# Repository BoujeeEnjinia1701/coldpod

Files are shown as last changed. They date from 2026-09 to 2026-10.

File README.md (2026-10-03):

# ColdPod

     

**Area:** BioMedical · **TRL:** 3 of 9 (proof of concept on paper) · **Value-engineering target:** $310 USD (hypothetical control target; estimated cost of the constructable design $313, $3 over the target) · **Difficulty:** 3 of 5

Portable Peltier cooler with a phase-change buffer and a temperature logger that raises alerts on excursions.

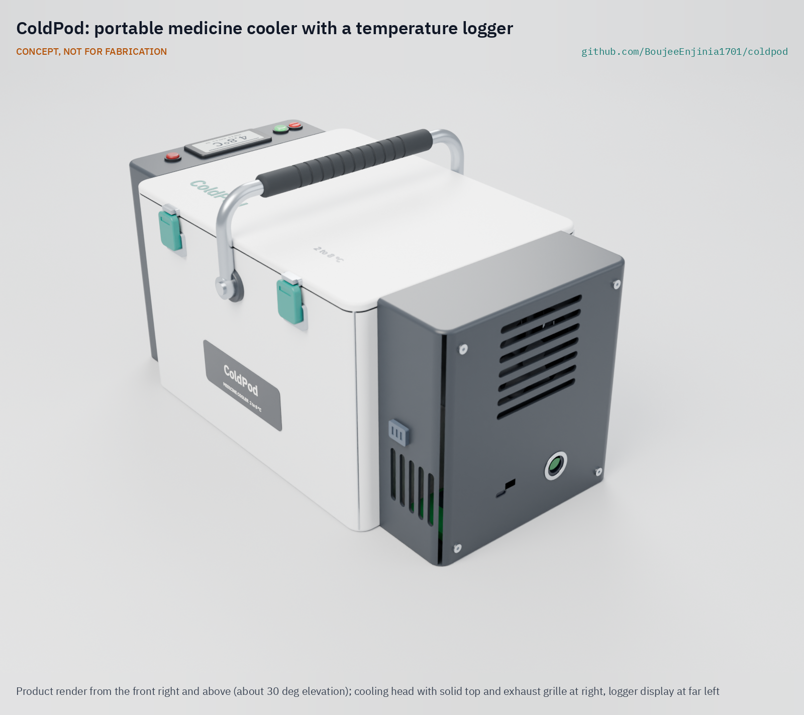
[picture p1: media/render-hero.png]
ColdPod: portable medicine cooler with a temperature logger, product render


[Exploded render](media/render-exploded.png) · [Detail render](media/render-detail.png) · [Interactive 3D model](media/viewer.html) · [Concept blueprint (PDF)](media/concept-blueprint.pdf) · [General arrangement CPD-DWG-001 (PDF)](cad/drawings/CPD-DWG-001.pdf) · [Sizing calculations](docs/04-calcs/01-sizing.md) · [Prototype build plan](docs/05-build-plan.md) · [Design decisions](docs/06-design-decisions.md) · [Review note](docs/REVIEW.md)

## Concept rationale

A vaccine or insulin carrier has to solve two problems at once: it must not let the load warm up, and it must not let it freeze. Ice packs solve the first badly and cause the second. ColdPod stores its cold in a phase-change material that melts at 5 °C, so the coldest thing next to the payload is still inside the 2 to 8 °C window. A small Peltier module recharges that store from a vehicle socket, a solar panel or a USB-C charger instead of a freezer, and a one-way thermosiphon stops the module from leaking heat back in when it is off. A logger with its own alarms records what the payload actually saw, so a health worker knows whether a load is still good.

It is open and garage-buildable because the gap is not the physics but access. Commercial active carriers exist, but they are closed products that a clinic, a university group or a maker space cannot inspect, repair or adapt. ColdPod uses printed parts, bought vacuum-insulated panels, off-the-shelf power modules and no custom circuit board, and it publishes its heat-leak, hold-time and fault calculations so that anyone can check them.

## Burning platform

Two very large groups depend on a cold chain that often fails at its last step. There are 589 million adults living with diabetes, 81 % of them in low- and middle-income countries ([IDF Diabetes Atlas, 11th edition, 2025](https://media.idf.org/media/uploads/sites/3/2025/04/IDF_Atlas_11th_Edition_2025_Global-Factsheet.pdf)), and many of those who use insulin must keep it at 2 to 8 °C and discard it if it freezes ([US FDA](https://www.fda.gov/drugs/emergency-preparedness-drugs/information-regarding-insulin-storage-and-switching-between-products-emergency)). Routine immunization still leaves 14.3 million infants a year without a single vaccine dose, half of them in countries affected by fragility, conflict or humanitarian crises, where carrying vaccines is hardest ([WHO and UNICEF, 2025](https://www.unicef.org/press-releases/global-childhood-vaccination-holds-steady-yet-over-14-million-infants-remain)).

Freezing, not only heat, is a common failure. A systematic review estimated that vaccines were exposed to temperatures below the recommended range in about 33 % of storage in wealthier countries and 37 % in lower-income countries, and in about 38 % and 19 % of shipments ([Hanson et al., *Vaccine*, 2017](https://www.sciencedirect.com/science/article/pii/S0264410X16309471)). Many of these events are never recorded, because the carrier has no logger.

## Where it could be used

### By industry

| Industry | Use |
| --- | --- |
| Public health and immunization programs | Outreach sessions on foot, bicycle or motorbike, with a record that the day's vaccines stayed in range |
| Humanitarian and disaster response | Insulin and vaccines carried where the grid is down, recharged from vehicles or solar panels |
| Community pharmacy and home delivery | Temperature-sensitive medicines delivered by van or motorbike with a trip log |
| Diabetes care and patient support | Travel and power-cut backup for people who carry a month of insulin |
| Clinical research and sample logistics | Short transfers of 2 to 8 °C research materials with a logged temperature history |
| Global health engineering education | An open, auditable reference design for cold chain teaching and research |

### By country or region

| Country or region | Why it matters there |
| --- | --- |
| Sub-Saharan Africa | Long outreach trips in heat with intermittent clinic power; WHO measures a vaccine carrier's cold life at a constant ambient temperature of 43 °C ([WHO PQS E004/VC01.2](https://extranet.who.int/pqweb/key-resources/documents/pqs-performance-specification-e004vc012-vaccine-carrier)) |
| South Asia | Very hot pre-monsoon seasons and dense rural outreach; the region is part of the low- and middle-income world where 81 % of adults with diabetes live ([IDF, 2025](https://media.idf.org/media/uploads/sites/3/2025/04/IDF_Atlas_11th_Edition_2025_Global-Factsheet.pdf)) |
| Countries affected by conflict or humanitarian crisis | Half of all unvaccinated children live in 26 fragile or crisis-affected countries ([WHO and UNICEF, 2025](https://www.unicef.org/press-releases/global-childhood-vaccination-holds-steady-yet-over-14-million-infants-remain)), where cold chain equipment and power are least reliable |
| Latin America, including the Amazon basin | In Colombia's Putumayo department, vaccination teams travel five to six hours by river to reach riverside communities ([PAHO, 2024](https://www.paho.org/en/stories/colombian-vaccination-team-donated-boat-makes-all-difference)), and in Panama some communities can be reached only by plane or boat ([PAHO](https://www.paho.org/en/stories/strengthening-cold-chain-operations-mission-take-vaccines-farthest-corners-region)) |
| United States and other high-income countries | Natural disasters and other emergencies can leave people with insulin but no working refrigerator; the FDA publishes storage guidance for these conditions ([US FDA](https://www.fda.gov/drugs/emergency-preparedness-drugs/information-regarding-insulin-storage-and-switching-between-products-emergency)), and freezing in storage is common even in wealthier countries ([Hanson et al., 2017](https://www.sciencedirect.com/science/article/pii/S0264410X16309471)) |

## What sparked the idea

The starting point was the vaccine vial monitor, the heat-sensitive label that WHO and PATH brought into use on oral polio vaccine in 1996 ([PATH](https://www.path.org/our-impact/articles/vaccine-vial-monitor-worlds-smartest-sticker/)). It showed that a cheap indicator travelling with each vial could change field practice, but it records only cumulative heat: training material for health workers states that vial monitors "do not measure exposure to freezing temperatures" and that a frozen vaccine may have lost its potency without the monitor showing it ([OpenLearn Create, Immunization module](https://www.open.edu/openlearncreate/mod/oucontent/view.php?id=53354&section=1.5.1)). ColdPod takes the next step for the carrier itself: prevent freezing by design, and log and alarm on both heat and cold.

## Problem

Insulin and vaccines spoil in field transport without a reliable cold chain. They must stay between 2 and 8 °C: ice packs run out in the heat, freeze vials when they are too cold, and usually nothing records what happened. Studies of the vaccine cold chain find freezing exposure in roughly a fifth to a third of storage and shipping studies. Design with, not for: requirements must come from co-design with health workers and people who carry insulin, through a local partner.

Full problem statement: [docs/01-problem.md](docs/01-problem.md)

## Concept

A carry case 366 x 220 x 207 mm holds 1.37 L of insulin or vaccines (24 insulin pens) in an aluminium liner wrapped in a phase-change material that melts at 5 °C, inside 25 mm vacuum-insulated panels. A Peltier module refreezes the phase-change material from a 12 V socket, a solar panel or a USB-C charger, through a loop thermosiphon that carries heat one way only; an aluminium cold plate tray round the lid pack lets it freeze that pack too. A 76.8 Wh LiFePO4 battery keeps it cooling on the road, and a logger records the payload temperature every minute and raises alarms on excursions.

TRL 3 calculations ([CPD-CAL-001](docs/04-calcs/01-sizing.md)): about 13.3 h with no power at 43 °C, 27.3 h off-grid at 32 °C and 16.7 h off-grid at 43 °C, all with thin margins. Two hardware cut-outs in series keep a stuck-on driver from freezing the payload. Refreezing all the phase-change material takes 8.0 h, within the 9 h overnight target, and the case weighs 5.74 kg empty now that every fixing is in, within the 5.75 kg prototype limit; Amish set both targets on 2026-10-02 ([design decisions register](docs/06-design-decisions.md)). Value-engineering target: USD 310 (a hypothetical control target, not a limit). Estimated cost of the constructable design: USD 313 (USD 3 over the target). TRL 4 (lab testing) is on hold.

Full design precis: [docs/02-concept.md](docs/02-concept.md)

## Key components

- Vacuum-insulated panels, 25 mm, in a printed shell
- Phase-change material packs, 5 °C, around an aluminium liner
- Aluminium evaporator can and loop thermosiphon (one-way) to a 40 mm Peltier module (TEC1-12703 class)
- Aluminium lid cold plate tray holding the lid phase-change pack
- Heat sink and fan in a vented cooling head
- LiFePO4 battery, 12.8 V 6 Ah (76.8 Wh), with BMS
- USB-C PD and 12 V power board with a buck-boost Peltier driver and two hardware freeze cut-outs (cold block and liner)
- nRF52840 logger with buffered payload probe, e-paper display and alarm

The working bill of materials is in [bom/bom.csv](bom/bom.csv).

## Building the prototype

The design is constructable: every part can be printed, folded, bent, machined or bought, and every part fixes to the next. Because a vacuum-insulated panel sits behind every wall, no screw goes through the shell; all outside fixings land on printed pads with threaded inserts. The [prototype build plan](docs/05-build-plan.md) shows each of the 15 made components on a making sketch and every one of the 20 assembly steps in a picture; the sealed copper loop is brazed and charged by a refrigeration technician before it goes in. It is a plan, not yet built; building to it is TRL 4 work.

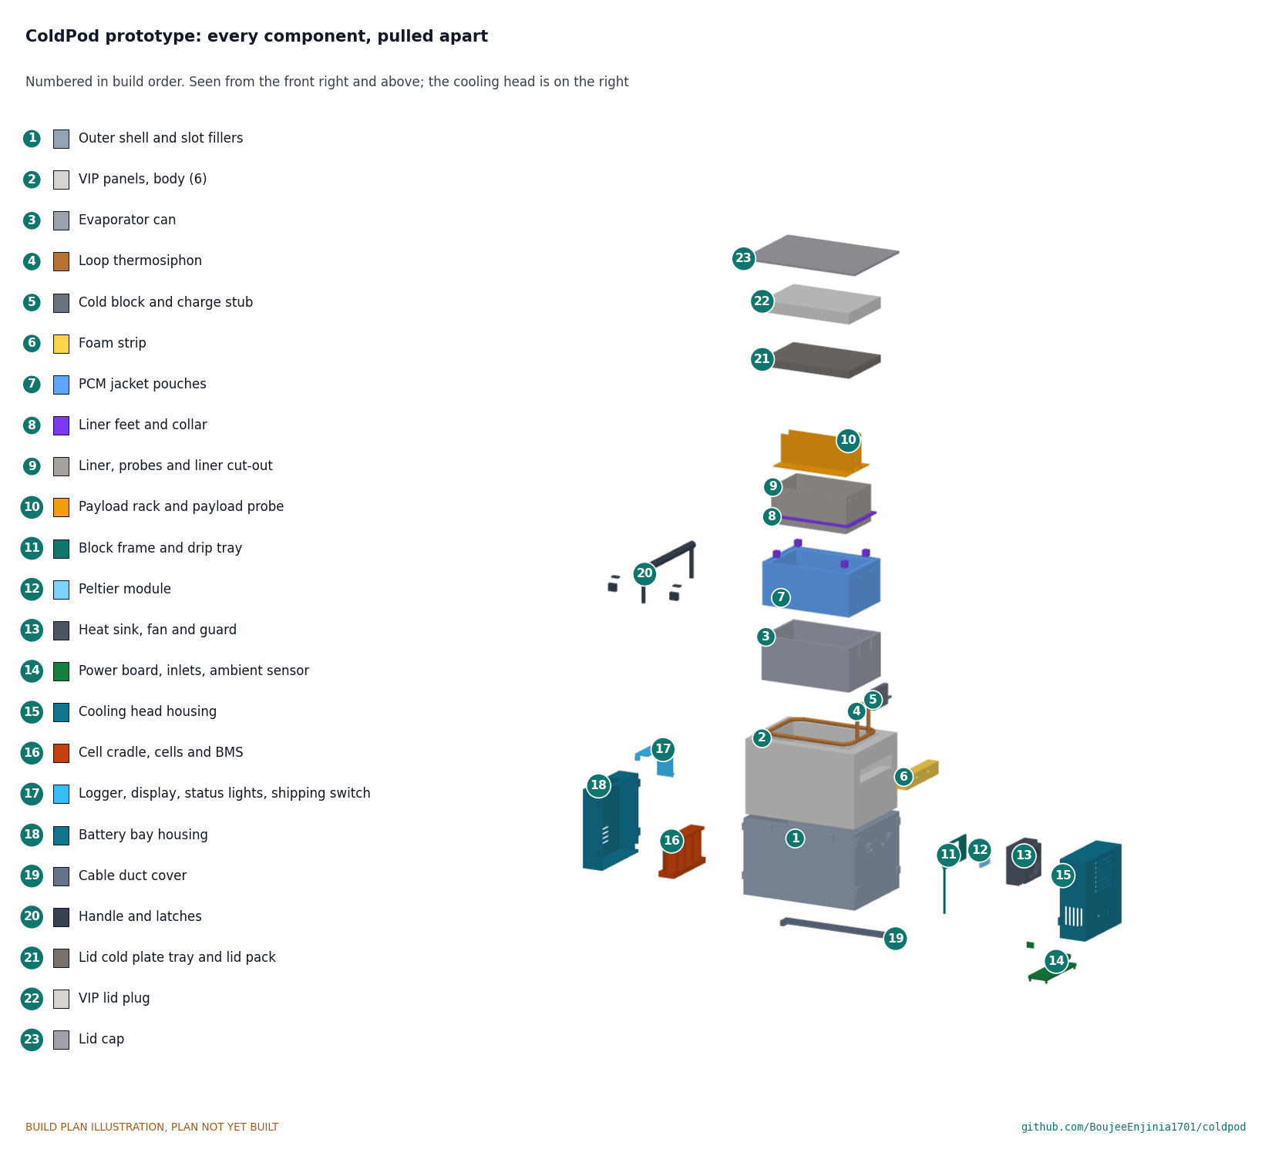
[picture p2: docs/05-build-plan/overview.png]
ColdPod prototype: every component, pulled apart and numbered in build order


## Safety

> This is a research and educational prototype. It is not a medical device, has not been cleared or approved by any regulator, is not WHO-prequalified, and must not be used to diagnose, treat or monitor any person or as the only protection for real vaccines or insulin.

It contains a lithium (LiFePO4) battery, a combustible paraffin phase-change material and a heat sink that can get hot. See the safety section of the [design precis](docs/02-concept.md#safety).

## Repository layout

| Folder | Contents |
| --- | --- |
| `docs/` | Problem, concept, requirements, calculations (`04-calcs/`) and design decisions (`decisions/`) |
| `cad/src/` | build123d Python source, the source of truth for all geometry |
| `cad/step/`, `cad/stl/` | Exported models for FreeCAD, other CAD tools and printing |
| `cad/drawings/` | 2D sketches and dimensioned drawings |
| `bom/` | Bill of materials |
| `electronics/` | KiCad schematics and PCB layouts |
| `firmware/` | Microcontroller code |
| `media/` | Renders, perspectives and photos |
| `build-log/` | Dated prototyping notes |

## Documentation

Controlled documents follow the portfolio [documentation standard](.kit/STANDARDS.md). Each carries a document ID (CPD-PRC-001 for the precis), a version and a revision history. Branded PDFs are built with `python .kit/render.py` and attached to GitHub Releases when a document is tagged, for example `CPD-PRC-001/v1.0`.

## Credits

Designed by Amish Chadha, with contributions from Dr. Geeti Chadha. See [CONTRIBUTORS.md](CONTRIBUTORS.md) for roles. To cite this design, use [CITATION.cff](CITATION.cff) (GitHub shows it as "Cite this repository").

AI assistance (Claude) was used to accelerate concept renders, prototype documentation and first-pass sizing calculations. Design direction and all decisions are Amish Chadha's, recorded in this repository's decision records (`docs/decisions/`).

## Licenses

- **Hardware** (CAD, drawings, BOM, electronics): [CERN-OHL-S v2](LICENSE)
- **Software** (firmware, scripts, notebooks): [MIT](LICENSE-SOFTWARE)

A project of the [Design Molecule](https://designmolecule.com) lab.

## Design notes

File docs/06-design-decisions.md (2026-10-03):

---
doc_id: CPD-DEC-001
title: ColdPod design decisions register
project: ColdPod
doc_type: Design decisions register
version: "0.5"
status: Draft
date: '2026-10-03'
author: Amish Chadha
license: CERN-OHL-S-2.0
revisions:
  - version: "0.1"
    date: '2026-10-01'
    author: Amish Chadha
    change: Register opened with the open decisions from the review note, the decision records and the build plan work
  - version: "0.2"
    date: '2026-10-01'
    author: Amish Chadha
    change: Budget treated as a value-engineering target
  - version: "0.3"
    date: '2026-10-02'
    author: Amish Chadha
    change: "Amish approved the recommendations for open decisions 1 to 7 (2026-10-02); moved to decisions made (CPD-DDR-003 accepted)"
  - version: "0.4"
    date: '2026-10-02'
    author: Amish Chadha
    change: "Value engineering restated after the approved follow-ups were carried into the model and BOM: USD 313, USD 3 over the target (battery shipping switch added)"
  - version: "0.5"
    date: '2026-10-03'
    author: Amish Chadha
    change: "Amish accepted the cost overrun against the value-engineering target on 2026-10-03; row added to decisions made; value engineering section updated"
---

# ColdPod design decisions register

Every design decision still to be made, and every decision made, in one place. Each decision is argued in full in its decision record under `docs/decisions/`; this register is the index Amish works from. The build plan (`docs/05-build-plan.md`) describes the design as it stands and does not list open decisions.

## Open decisions

None. All open decisions were decided on 2026-10-02.

## To confirm when parts are bought

| # | What to confirm | Why it matters | Source |
| --- | --- | --- | --- |
| 1 | The VIP maker can supply the seven panels to plus 0, minus 1 mm, with a quote and aged conductivity and edge data | The panels fill the shell exactly; joints and edges are about 45 % of the heat leak | CPD-DDR-003; CPD-CAL-001 |
| 2 | The gasket still seals with the lid tray landed on the can flange, and the tray seat gives about 0.5 K/W | Lid seal and lid-pack refreeze both rest on it | CPD-DDR-002; CPD-CAL-001 |
| 3 | The PCM maker can supply the eight pouch shapes, and the usable latent heat between 2 and 8 °C | Pouch fit round the risers and feet; hold times | CPD-DDR-003; CPD-CAL-001 |
| 4 | The bought handle's pivot eyes take M5 screws and clear the 4 mm pads | Handle pivot pads | CPD-DDR-003 |
| 5 | The off-state conductance and real COP of the chosen module with the chosen heat sink and fan | Hold power and the thermosiphon diode ratio | CPD-PRC-001 |
| 6 | The Peltier driver can run the module from a 10 V input | R7 at the low end of the vehicle range | CPD-DDR-002 |
| 7 | Whether a motorbike carrier stays within about 19° of tilt with the cooling head down; if not, the mechanical disconnect fallback | The loop thermosiphon works only below that tilt | CPD-DDR-001, D2; CPD-CAL-001, H5 |

## Value engineering

Value-engineering target: USD 310 (a hypothetical control target, not a limit). Estimated cost of the constructable design: USD 313 (USD 3 over the target).

Amish accepted this overrun on 2026-10-03: the estimated cost of USD 313 against the USD 310 target (USD 3 over), keeping the USD 5 battery shipping switch (BOM line 18). Amish: "Cost over target - i accept all the cost variations and overruns". It stays reported against the target as an accepted overrun, and the savings below remain worth trying.

- **Main cost drivers:** the vacuum-insulated panel set (about USD 60, still an estimate until quoted), the thermosiphon loop (about USD 28), the buck-boost Peltier driver (USD 22 to 26), the lid cold plate tray (USD 13) and the liner cut-out (USD 10 to 13).
- **Savings worth trying:** a VIP quote before any purchase; thinner printed parts, which already saved about USD 4 of filament; and re-pricing the driver and thermosiphon parts at purchase; the USD 5 shipping switch could wait until a trip needs it, which would bring the cost back to USD 308.

## Decisions made

| Date | Decision | Decided by | Record |
| --- | --- | --- | --- |
| 2026-09-25 | TRL 2 review items D1 to D11: 5 °C organic PCM, thermosiphon with a mechanical disconnect as fallback, evaporator on the outer face of the PCM, 76.8 Wh LiFePO4 pack, R6 redefined to 16 h, R12 relaxed to 5.5 kg, VIPs with a foam variant documented, local alarms and Bluetooth only, alarm defaults, budget $300, outreach vaccinators first | Amish, going with the recommendation | CPD-DDR-001 |
| 2026-09-25 | TRL 3 recommendations: lid cold plate, 3 °C liner cut-out, thinner printed parts, evaporator can and loop thermosiphon, TEC1-12703 class with smooth DC, buck-boost driver, budget kept at $300 | Amish: "i accept all your recommendations, go with them across all repos." | CPD-DDR-002 |
| 2026-09-26 | Budget top-up to $310 (R15 met) | Amish: "I am ok with the budget top ups" | CPD-DDR-002, N3 |
| 2026-09-30 | Make the design physically buildable while drawing the build plan | Amish: "If you are realising that the design cannot be built as per concept - fix the design assumptions to match and be physically feasible as you draw the illustrations." The changes themselves were accepted on 2026-10-02 (below) | CPD-DDR-003 |
| 2026-10-02 | Design for construction accepted: the changes P1 to P12 (pads and towers on the shell, rim slots, foam strip, loop in the can corner, block frame, liner feet and collar, folded lid tray, fixings, drip tray, cable duct) and their knock-on changes, as made | Amish: "i approve your recommendations for all 555 open decisions." | CPD-DDR-003, A1 |
| 2026-10-02 | Mass (R12): option (a). R12 relaxed to 5.75 kg for the prototype, which is weighed at TRL 4; the base bumper is left off so the 0.05 kg margin is not spent before weighing | Amish: "i approve your recommendations for all 555 open decisions." | CPD-DDR-003, A2; CPD-DDR-002, N2 |
| 2026-10-02 | Refreeze (R8): option (a). R8 restated as 9 h or less for all the PCM at 25 °C, still an overnight refreeze | Amish: "i approve your recommendations for all 555 open decisions." | CPD-DDR-002, N1; CPD-CAL-001 v0.4, G4 |
| 2026-10-02 | Battery removal (R14): option (a) for the prototype; the battery bay on four screws counts as removable. Before any field or air travel use, add the shipping switch and check the carrier's lithium battery rules. The switch is now in the model and the BOM (line 18, USD 5), which took the cost from USD 308 to USD 313 | Amish: "i approve your recommendations for all 555 open decisions." | CPD-DDR-003, A3 |
| 2026-10-02 | Loop working fluid: R-134a (non-flammable, safety class A1) for the prototype, with the charge set by the refrigeration technician from the loop volume; a lower-impact fluid such as R-1234yf (A2L, mildly flammable) is revisited only for a product version and under local rules | Amish: "i approve your recommendations for all 555 open decisions." | CPD-DDR-003, A4 |
| 2026-10-02 | Co-design partner: an immunization program, consistent with outreach vaccinators first (CPD-DDR-001, D11). First candidate to approach: PATH, or a national immunization program's outreach team reached through it | Amish: "i approve your recommendations for all 555 open decisions." | CPD-DDR-001, O1 |
| 2026-10-02 | Appearance model: round bail in the model; heat sink kept solid (no window); second status light adopted; labels and wordmark under BOM line 16; base bumper left out until the prototype is weighed | Amish: "i approve your recommendations for all 555 open decisions." | `docs/REVIEW.md`, 2026-09-26 |
| 2026-10-03 | Cost overrun accepted: the estimated cost of USD 313 against the USD 310 target (USD 3 over), keeping the USD 5 battery shipping switch (BOM line 18) | Amish: "Cost over target - i accept all the cost variations and overruns" | [REVIEW.md](REVIEW.md), session 2026-10-03 |

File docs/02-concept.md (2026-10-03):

---
doc_id: CPD-PRC-001
title: ColdPod design precis
project: ColdPod
doc_type: Design precis
version: "0.9"
status: Draft
date: '2026-10-02'
author: Amish Chadha
license: CERN-OHL-S-2.0
revisions:
- version: "0.1"
  date: '2026-09-24'
  author: Amish Chadha
  change: Initial scaffold
- version: "0.2"
  date: '2026-09-25'
  author: Amish Chadha
  change: Populate to TRL 2 (architecture, first-order numbers, design choices, safety, media)
- version: "0.3"
  date: '2026-09-25'
  author: Amish Chadha
  change: Record Amish's decisions (CPD-DDR-001); numbers replaced by CPD-CAL-001; evaporator can, loop thermosiphon and TEC1-12703 class sized; smooth DC drive
- version: "0.4"
  date: '2026-09-25'
  author: Amish Chadha
  change: Recommendations accepted by Amish (DDR-002). Lid cold plate, liner cut-out at 3 °C, thinner printed parts and buck-boost driver; numbers from CPD-CAL-001 v0.2
- version: "0.5"
  date: '2026-09-26'
  author: Amish Chadha
  change: Budget top-up approved by Amish; budget $310, R15 met
- version: "0.6"
  date: '2026-10-01'
  author: Amish Chadha
  change: Constructable design (CPD-DDR-003, Draft, open for Amish's review); numbers from CPD-CAL-001 v0.4; build plan CPD-BLD-001 and decisions register CPD-DEC-001 added
- version: "0.7"
  date: '2026-10-01'
  author: Amish Chadha
  change: Budget treated as a value-engineering target
- version: "0.8"
  date: '2026-10-02'
  author: Amish Chadha
  change: "Decisions of 2026-10-02: CPD-DDR-003 accepted; R8 restated as 9 h and R12 relaxed to 5.75 kg; R-134a and battery removal safety rules; first partner candidate"
- version: "0.9"
  date: '2026-10-02'
  author: Amish Chadha
  change: "Figures from CPD-CAL-001 v0.7: 5.74 kg, $313 ($3 over the value-engineering target); battery shipping switch (item 18) and second status light added to the model and BOM"
---

# ColdPod design precis

ColdPod is a carry case about the size of a lunch cooler (366 x 220 x 207 mm) that holds 1.37 L of insulin or vaccines (24 pens) at 2 to 8 °C. The payload sits in an aluminium liner wrapped in a phase-change material (PCM) that melts at 5 °C, inside 25 mm vacuum-insulated panels. A Peltier module freezes the PCM from a 12 V socket, a solar panel or a USB-C charger, and a small LiFePO4 battery keeps it running on the road. A two-phase loop thermosiphon connects the two and carries heat in one direction only, so a stopped Peltier does not leak heat back in. A logger records the payload temperature every minute and raises alarms. An aluminium cold plate tray holding the lid PCM pack lands on the evaporator can's rim flange when the lid closes, so the Peltier freezes all the PCM, and a second hardware cut-out on the liner stops a stuck-on driver from freezing the payload. Version 0.6 describes the constructable design of CPD-DDR-003 (Draft, open for Amish's review), in which every part can be made and fixed; the prototype build plan is CPD-BLD-001 and open decisions are in the register CPD-DEC-001. The TRL 3 calculations (CPD-CAL-001 v0.7) give about 13.3 h with no power at 43 °C, 27.3 h off-grid at 32 °C and 16.7 h off-grid at 43 °C, for $313 in parts and 5.74 kg empty. The hold times meet their targets with thin margins. Refreezing all the PCM takes 8.0 h and the case weighs 5.74 kg; on 2026-10-02 Amish restated R8 as 9 h and relaxed R12 to 5.75 kg for the prototype, so both are met on paper (R12 with 0.05 kg of margin, to be weighed at TRL 4). The parts cost is within the $310 budget that Amish approved on 2026-09-26 (R15 met).

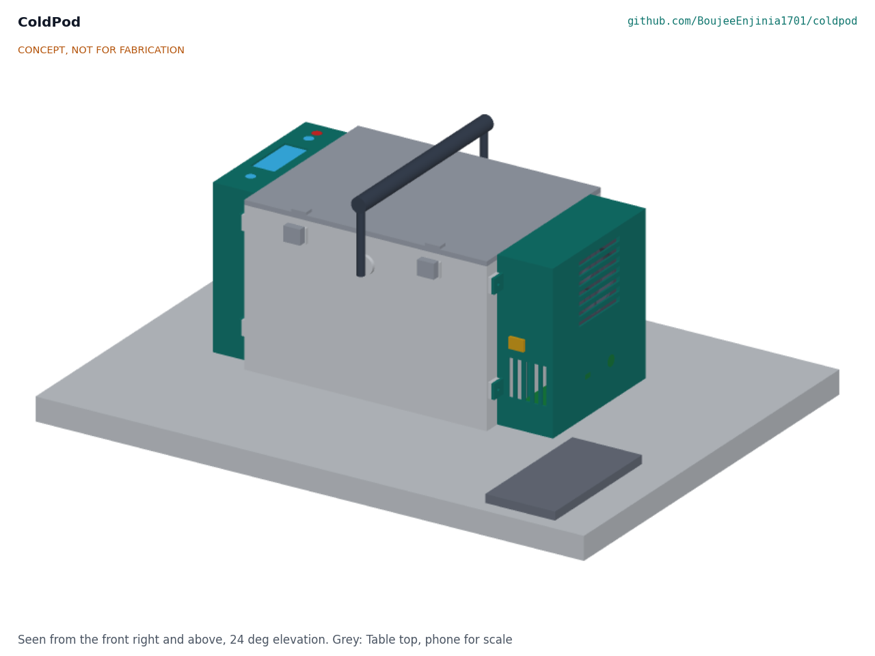
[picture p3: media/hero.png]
Hero render


*Figure 1. ColdPod on a table, with a phone for scale. Cooling head on the right end, battery and electronics bay with the e-paper display on the left end. Rendered from the parametric model `cad/src/model.py`.*

## How it works

1. **Charge the cold.** At a clinic, in a vehicle or under a solar panel, the Peltier module runs at up to 25 W and freezes the PCM jacket through the thermosiphon and the aluminium evaporator can around it. The lid PCM pack sits in a 1.5 mm aluminium cold plate tray that lands on the can's rim flange when the lid closes, so it freezes through the can too. The same input charges the battery at about 12 W. A fully melted charge refreezes in about 8.0 h (the jacket in 6.8 h). The case works best if the payload goes in already cold from a refrigerator.
2. **Carry.** On the road, the controller runs the Peltier from the battery only as hard as needed to hold the evaporator can at about 2 °C, so the PCM stays frozen, and turns it off when the battery reaches 15 % so that the logger always has a reserve. A buck-boost driver feeds the module smooth DC from any input between 10 and 20 V; on/off PWM would cost about 60 % more power at 43 °C. The lid pack stays frozen on its plate.
3. **Hold passively.** When the battery is flat or the user switches cooling off, the PCM absorbs the heat that leaks through the walls; the plate lets the jacket and lid pack share the load. Because it melts at 5 °C, it cannot pull the payload below freezing the way water ice can.
4. **Watch.** A buffered probe among the payload, a liner probe, a cold-block probe and an ambient sensor are read every minute. The payload probe is logged with a timestamp on the controller's flash memory for 60 days or more.
5. **Alarm.** The display shows current, minimum and maximum temperature and time left. A buzzer, an LED and a phone notification warn after 10 min outside 2 to 8 °C, alarm at once at 0 °C or lower, and flag low battery, a failed sensor or a lid left open. The owner exports the log as a CSV file over Bluetooth Low Energy or USB. Nothing goes to the cloud.

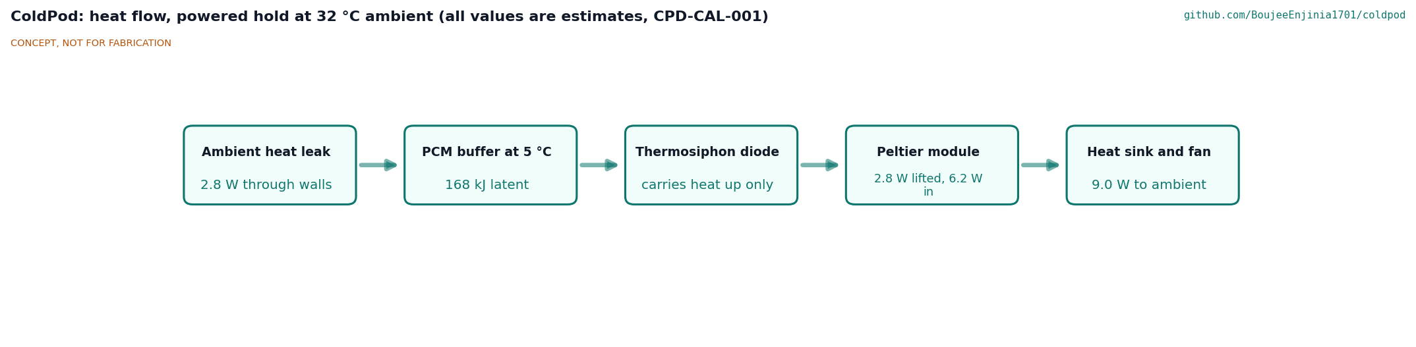
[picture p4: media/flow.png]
Heat flow


*Figure 2. Heat flow in powered hold at 32 °C ambient, can at 2 °C. All values are estimates from CPD-CAL-001: 0.092 W/K overall heat leak, TEC1-12703 class module at a coefficient of performance (COP) of 0.45, fan 0.6 W.*

## Main components

Table 1. Main components. Numbers match `bom/bom.csv` and Figure 4.

| # | Component | Proposed choice | Notes |
| --- | --- | --- | --- |
| 1 | Outer shell | 3D-printed PETG or ASA tub, 3 mm walls, 261 x 196 x 164.5 mm, with printed pads and towers carrying threaded inserts for every outside fixing, and pipe and cable slots closed by printed fillers | Protects the VIPs from knocks and punctures; no fixing passes through a wall (CPD-DDR-003) |
| 2 | Lid and lid cold plate | Printed 5 mm cap with EPDM gasket and a 25 mm VIP plug; 1.5 mm aluminium cold plate tray, 204 x 139 x 16.5 mm, holding the lid PCM pack and bonded to the plug | Two front draw latches; lid switch for the lid-open alarm; the tray lands on the can's rim flange so the lid pack freezes and stays frozen |
| 3 | Bail handle and strap | Folding bail handle, padded shoulder strap | Rated 10 kg or more |
| 4 | Vacuum-insulated panels | Seven panels, 25 mm, fumed silica core, ordered to size, and a 28 mm foam strip | VIPs cannot be cut or pierced; the heat-pipe crossing is a foam-filled gap between panels |
| 5 | PCM packs | About 0.94 kg of organic PCM melting at 5 °C (Rubitherm RT 5 HC class) in sealed HDPE pouches: a 0.67 kg jacket on four sides and the floor inside the evaporator can, and a 0.27 kg pack in the lid tray | Organic paraffins are stable for thousands of cycles ([PATH PCM study](https://media.path.org/documents/DT_pcm_summary_rpt1.pdf)) |
| 6 | Liner and rack | 1.5 mm aluminium can, 175 x 110 x 80 mm outside (172 x 107 x 78.5 mm inside), with a removable printed rack for 24 pens in four layers of six; stands on printed feet with a printed collar, never touching the can | Spreads cold evenly around the payload |
| 7 | Evaporator can and thermosiphon | 1.0 mm aluminium can lining the outer face of the PCM jacket (four sides and floor); two-phase loop thermosiphon: 8 mm copper evaporator loop bonded into the bottom corner of the can, vapour riser and liquid return at the +X end, stainless sections through the wall, aluminium cold block 81 mm above the loop, held to the shell by a printed frame | One-way thermal link (design choices 2 and 3); sized in CPD-CAL-001, section G |
| 8 | Peltier module | 40 x 40 mm, 127 couples, Imax about 3 A (TEC1-12703 class) | The TEC1-12706 cannot hold at 43 °C: its off-state conduction is too high (CPD-CAL-001, section E) |
| 9 | Heat sink and fan | Finned aluminium sink, 80 x 80 x 30 mm, 0.50 K/W or better with a 70 mm, 12 V fan and a finger guard | Rejects about 8.9 W at 32 °C and 19.7 W at 43 °C |
| 10 | End housings | Printed cooling head (+X end) and battery and electronics bay (−X end), 2 mm walls, vented | Keep the heat source and the battery outside the insulation |
| 11 | Battery | LiFePO4, 4S1P 32700 cells, 12.8 V 6 Ah (76.8 Wh), BMS and fuse | Below the 100 Wh airline limit |
| 12 | Power board | USB-C PD sink (20 V), 12 V input (10 to 15 V) with reverse-polarity protection, LiFePO4 charger, buck-boost Peltier driver with an LC filter, fan driver; the cold-block and liner cut-outs wired in series in the Peltier supply | Off-the-shelf modules on perfboard; no custom PCB |
| 13 | Logger controller | nRF52840 module with real-time clock and 2 MB flash | Bluetooth Low Energy link to a phone |
| 14 | Temperature sensors and liner cut-out | Glycol-buffered payload probe, liner probe, cold-block probe, ambient sensor; bimetal cut-out on the liner opening at 3 °C | Digital sensors with ±0.5 °C or better accuracy; the cut-out works without firmware |
| 15 | Display and alarm | 2.13 in e-paper, buzzer, two status lights (green and red, mirrored either side of the display) | E-paper keeps the last reading visible with no power |
| 18 | Battery shipping switch | Panel-mount rotary isolator, flush in the bay top, in series with the pack positive lead ahead of the fuse | Isolates the pack before any field or air travel (decided 2026-10-02) |

Item 16 (wiring, fasteners, latches and consumables) is in the BOM but not modelled; item 17 (printed construction parts) is in the model.

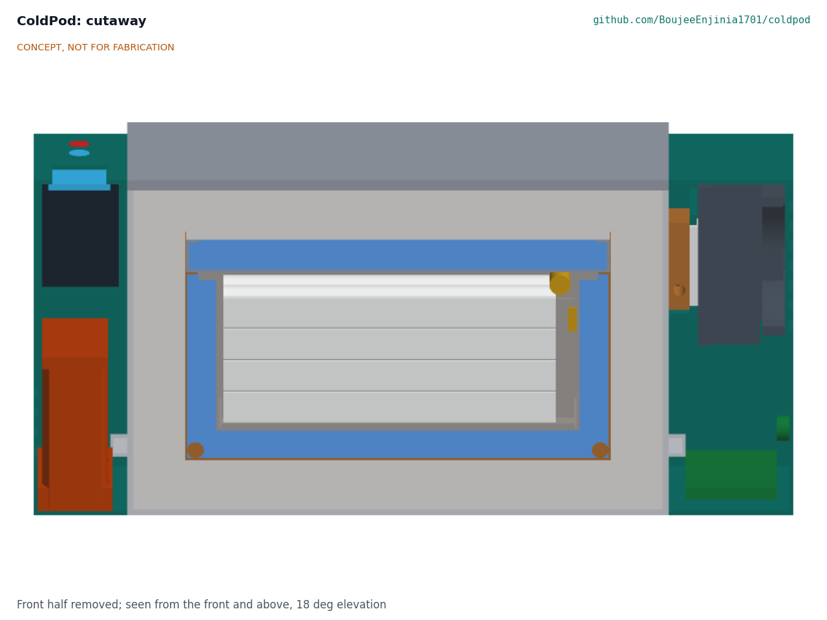
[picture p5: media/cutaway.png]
Cutaway


*Figure 3. Section looking from the front. From the inside out: payload (white pens) in the rack and liner (6), PCM jacket and lid pack (5, blue) with the evaporator can and its loop (7, copper; the loop shows as two circles at the base), the lid cold plate (2) under the lid pack, VIPs (4, light grey) and shell (1). The pipes (7) cross the right wall to the cold block, Peltier (8) and heat sink (9) in the cooling head. The battery (11) and logger (13) are in the left bay.*

## Numbers at TRL 3

All values come from the calculation note CPD-CAL-001 (`docs/04-calcs/01-sizing.md`), which states every assumption; the tags in brackets point to lines of its script, `docs/04-calcs/sizing.py`. They are paper estimates. The main inputs are an aged VIP conductivity of 0.007 W/(m·K) with explicit joint and edge losses, 180 kJ/kg of usable latent heat inside 2 to 8 °C for the PCM ([Rubitherm RT range](https://www.rubitherm.eu/en/productcategory/organische-pcm-rt)), a Peltier model derived from datasheet maxima (single-stage modules typically reach a COP of 0.3 to 0.7, [ThermalLM](https://thermallm.com/cop-of-a-thermoelectric-cooler-tec/)), and 65.3 Wh of the 76.8 Wh battery available for cooling.

Table 2. Hold times, charging, size, mass and cost.

| Quantity | Value | Basis | Requirement |
| --- | --- | --- | --- |
| Payload | 1.37 L; 24 insulin pens in four layers of six, up to 172 mm long | Liner less rack and probe [A2, A3] | R3 met |
| Heat leak | 0.093 W/K: 1.86 W at 25 °C, 2.50 W at 32 °C, 3.53 W at 43 °C | Langmuir shape factor, joints, foam strip, pipes, wires [B9, B10] | |
| PCM | 0.935 kg, 168 kJ (46.8 Wh) usable | Jacket 0.670 kg, lid pack 0.265 kg, measured on the model [C2, C3] | |
| Passive hold, PCM only | 25.2 h at 25 °C, 18.7 h at 32 °C, **13.3 h at 43 °C** | Jacket and lid pack pooled through the lid cold plate [D1, D2] | R4 at risk (10.2 h at +30 % leak) |
| Input power to hold | 4.2 W at 25 °C, 7.6 W at 32 °C, 18.8 W at 43 °C | TEC1-12703 class, can at 2 °C, buck-boost driver [E3] | R7 met |
| Battery hold, then PCM | 15.4 + 25.2 = 40.6 h at 25 °C; 8.6 + 18.7 = **27.3 h at 32 °C**; 3.5 + 13.3 = **16.7 h at 43 °C** | 65.3 Wh, then the PCM [F2] | R5 and R6 at risk |
| PCM refreeze from melted | **8.0 h** (8.03 h) for all the PCM at 25 °C (jacket 6.8 h, lid pack 8.0 h) | Time-stepped model, 25 W to the module [G4] | R8 met (9 h, restated 2026-10-02) |
| Battery recharge | about 6.7 h at 12 W alongside the refreeze | 45 W USB-C PD budget [G8] | |
| Heat rejected at the heat sink | 5.3 W at 25 °C, 9.0 W at 32 °C, 20.1 W at 43 °C; sink base about 53 °C at 43 °C | Heat lifted plus module input [E6, E7] | Fan needed |
| Thermosiphon | Forward 2.50 W/K, reverse 0.0058 W/K; full function to 19° of tilt with the cooling head down | [H1, H5] | |
| Freeze fault | Liner settles near 2.0 °C after a stuck-on driver, with the 3 °C liner cut-out | Lumped estimate [I5] | R2 met |
| Logger reserve | about 96 days | 15 % of 76.8 Wh at a 5 mW allowance [J4] | R11 met |
| Log storage | 1.38 MB for 60 days | 1 record per minute, 16 bytes [J1] | R9 met on 2 MB flash |
| Size | 366 x 220 x 207 mm (14.4 x 8.7 x 8.1 in) overall | Handle up [A6] | R13 met |
| Mass, empty | **5.74 kg (12.7 lb)** | Model volumes and densities [K2]; the fixings and parts that make the design buildable add about 0.17 kg (CPD-DDR-003) | R12 met on paper (5.75 kg for the prototype, 2026-10-02) |
| Parts cost | **$313** | `bom/bom.csv` [L2] | R15 over the value-engineering target ($310) by $3 |

## Key design choices

Amish decided choices 1 to 9 on 2026-09-25, going with the recommendation in each case (CPD-DDR-001). The options are kept here for the record.

1. **PCM at 5 °C instead of water ice (decided, D1).** Water ice stores about 334 kJ/kg, nearly twice as much, but a frozen ice pack sits at 0 °C or below and is a known cause of vaccine freezing ([Hanson et al., 2017](https://www.sciencedirect.com/science/article/pii/S0264410X16309471)). A 5 °C PCM keeps the whole payload space inside the window. Options were (a) 5 °C organic PCM; (b) water with a conditioning step; (c) a 3 °C PCM. Decision: (a).
2. **A thermosiphon between the Peltier and the PCM (decided, D2).** A Peltier module that is switched off conducts heat well: 0.27 W/K for the chosen module, about three times the whole box's heat leak. Bolted straight to the liner, it would cut the passive hold at 43 °C to about 3.6 h. A gravity thermosiphon, with its condenser above its evaporator, only carries heat upward and out, so it acts as a thermal diode (forward to reverse ratio about 430). Options were (a) thermosiphon; (b) a mechanical disconnect that lifts the cold block away when power is lost; (c) direct mounting. Decision: (a), with (b) as the fallback if the thermosiphon cannot be made reliable at this size. TRL 3 sizes it as a two-phase loop.
3. **Evaporator on the outer face of the PCM, not on the liner (decided, D3).** Keeps the coldest surface (down to −2 °C during refreezing) separated from the payload by the PCM, which supports R2. At TRL 3 this is sized as an aluminium can lining the outer face of the jacket, because a small plate cannot freeze a paraffin jacket that wraps the liner.
4. **LiFePO4, 76.8 Wh (decided, D4).** LiFePO4 tolerates heat better than other lithium-ion chemistries and 76.8 Wh stays under the 100 Wh airline limit. The rejected 4S2P option (153.6 Wh, about $30 more and 0.6 kg heavier) would give about 18.6 h at 43 °C off-grid.
5. **R6 redefined (decided, D5).** Accept about 16 h at 43 °C off-grid and run from a vehicle 12 V socket or a solar panel on long hot trips, rather than a larger battery or 35 mm VIPs with 1.6 kg of PCM (about 400 mm long and over 6 kg). Revisit after field data on real trip temperatures.
6. **Vacuum-insulated panels instead of foam (decided, D7).** Polyurethane foam of the same thickness (about 0.024 W/(m·K)) gives 0.161 W/K rather than 0.092 W/K, so the passive hold at 43 °C would drop from 13.3 h to about 7.6 h (CPD-CAL-001, P1 and P2), but it would save about $45 and some mass. VIPs are used, with a foam version documented as a low-cost variant.
7. **Local alarms and Bluetooth Low Energy only (decided, D8).** No cellular or LoRa radio in the first build (either would add $20 to $40 and more power).
8. **Alarm thresholds (decided, D9).** Warn after 10 min outside 2 to 8 °C; alarm at once at 0 °C or lower on the payload probe; alarm if the liner probe reaches 1 °C (an early freeze warning); adjustable per product.
9. **Value-engineering target (decided, D10).** The target is $310 (a hypothetical control target, not a limit; $300 at D10, $310 after CPD-DDR-002 item 16); the estimated parts cost of the constructable design is $313, $3 over the target (the $5 battery shipping switch added on 2026-10-02 took it from $308 to $313).

Amish decided the TRL 3 review items on 2026-09-25, again going with the recommendation in each case (CPD-DDR-002):

10. **Lid cold plate (decided, DDR-002 item 2).** A 1.5 mm aluminium plate under the lid PCM pack, whose rim seats on the evaporator can rim when the lid closes (about $5 and 0.12 kg). It gives the lid pack a cold path, so the Peltier refreezes all the PCM and the lid pack stays frozen in long powered holds. The other options were no lid pack with a 20 mm jacket, or conditioning the lid pack in a refrigerator. The gasket must still seal with the plate in place; that is a check for a built lid.
11. **Liner cut-out at 3 °C (decided, DDR-002 item 3).** A bimetal cut-out on the liner, in series with the −5 °C cold-block cut-out in the Peltier supply (about $3). After a stuck-on driver fault the liner settles near 2.0 °C.
12. **Thinner printed parts (decided, DDR-002 item 4).** Shell 3 mm (was 4 mm), lid cap 5 mm (was 8 mm), end housings 2 mm (was 3 mm), saving about 0.21 kg. Confirming the mass by weighing is TRL 4 work, on hold.
13. **Evaporator can and loop thermosiphon confirmed (decided, DDR-002 item 5).** As sized in CPD-CAL-001: a 1.0 mm aluminium can around the jacket fed by an 8 mm copper loop. The mechanical disconnect (choice 2b) stays ready as the fallback if a maker cannot charge the loop.
14. **Peltier class and drive confirmed (decided, DDR-002 item 6).** TEC1-12703 class module, smooth DC through an LC filter, heat sink of 0.50 K/W or better with the fan.
15. **Buck-boost driver (decided, DDR-002 item 7).** The Peltier driver can raise the module voltage above a low vehicle input (10 V), rather than narrowing the 12 V input range to 11 to 15 V (about $4 more).
16. **Value-engineering target of $310 (decided by Amish, DDR-002 item 8 and N3).** A VIP quote is to come before any purchase decision; purchasing is TRL 4 work, on hold.

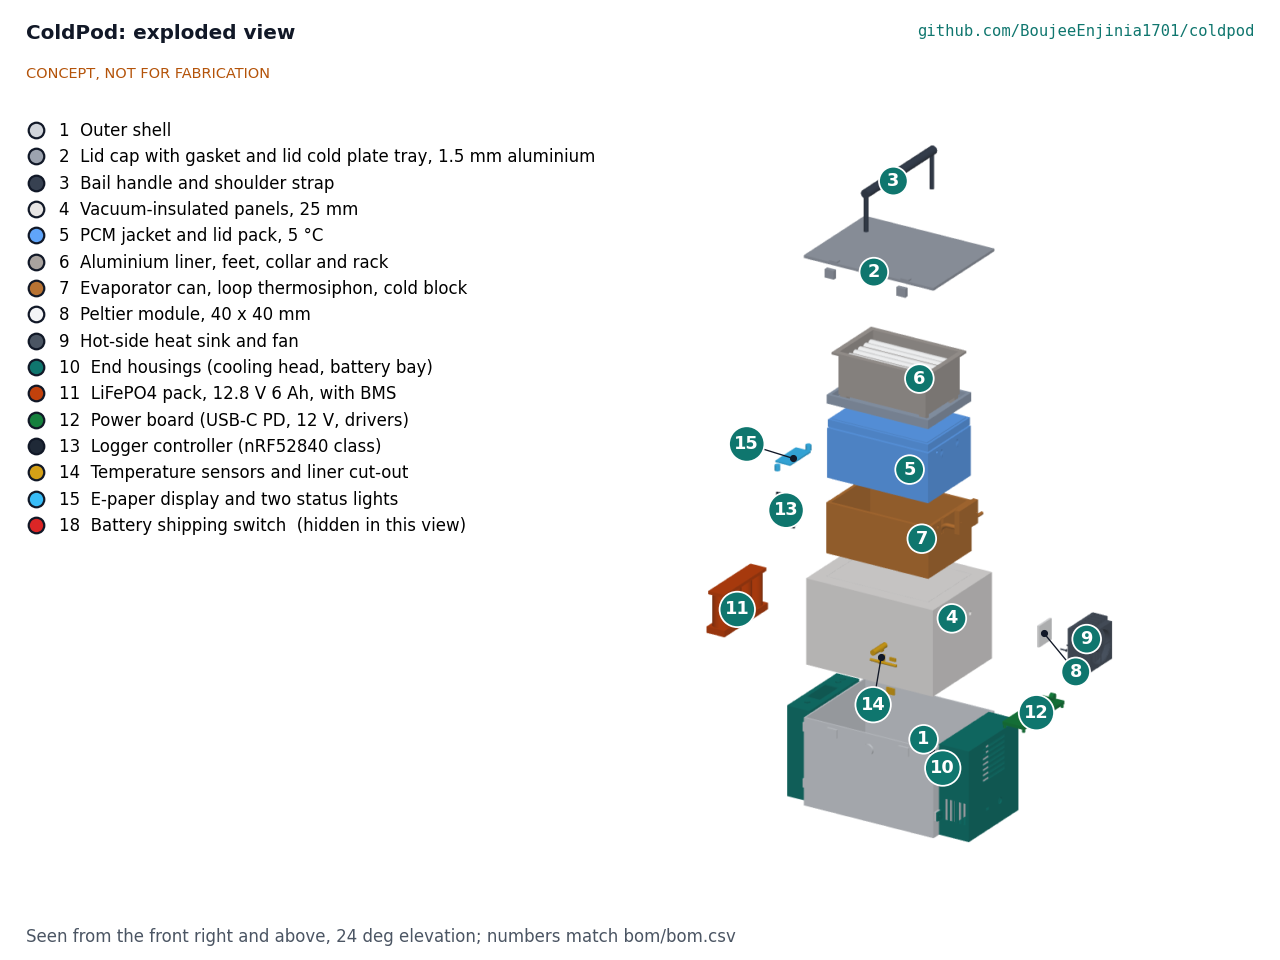
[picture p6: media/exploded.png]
Exploded view


*Figure 4. Exploded view with BOM numbers, from the parametric model. The payload pens rise with the liner (6); the evaporator can, loop and cold block (7) sit between the VIPs (4) and the PCM (5).*

## Safety

> **Safety:** ColdPod is a research and educational prototype. It is not a medical device, is not WHO-prequalified and has not been cleared or approved by any regulator. Do not use it as the only protection for vaccines, insulin or other medicines. Follow national immunization program and manufacturer storage instructions, and use a qualified carrier and a calibrated logger for real products.

> **Safety:** The LiFePO4 pack stores 76.8 Wh. Use it only with its BMS and fuse, charge it only between 0 and 45 °C (the controller must block charging outside that range), and never charge a damaged, swollen or wet pack. The battery sits in its own vented bay outside the insulation, away from the Peltier's hot side. For the prototype the pack is removed with the bay (four screws); before any field or air travel use a shipping switch is added and the carrier's lithium battery rules are checked (CPD-DDR-003 A3).

> **Safety:** The PCM is a paraffin, which is combustible. It stays sealed in HDPE pouches, separated from the battery bay by the VIPs and the shell. Replace any leaking pouch; paraffin can also soften some plastics ([PATH PCM study](https://media.path.org/documents/DT_pcm_summary_rpt1.pdf)).

- **Hot surfaces.** At 43 °C ambient the heat sink base reaches about 53 °C (estimate, CPD-CAL-001, E7). It is enclosed by the vented cooling head, and the vents must not be blocked, covered or placed against skin or a bag.
- **Moving parts.** The fan has a finger guard inside the cooling head grille.
- **Electrical.** All voltages are 20 V DC or less. There are no mains-voltage parts in the box. Inputs are fused and protected against reverse polarity.
- **Freezing fault.** A stuck-on Peltier driver is the main way to freeze the payload. Two hardware thermostats in series cut power to the Peltier independent of the firmware: one on the cold block at −5 °C and one on the liner at 3 °C. CPD-CAL-001 (section I) shows that the cold-block cut-out alone would let the liner follow the can down to about −4 °C; with the liner cut-out the liner settles near 2.0 °C. The liner and payload probes also raise alarms. The lid cold plate reaches −2 °C only while refreezing, which is done with the box empty; it touches no payload.
- **Refrigerant.** The loop is charged with R-134a, a non-flammable refrigerant (safety class A1), chosen because the loop sits beside a lithium battery in a hand-carried box; the refrigeration technician sets the charge from the loop volume. A mildly flammable fluid such as R-1234yf is considered only for a product version and under local rules (CPD-DDR-003 A4).
- **Condensation.** Water condenses on the cold block and pipes. The cooling head drains outward and the electronics are conformal-coated.
- **VIP damage.** A punctured VIP loses most of its insulation value without any visible change. The shell protects the panels, and a rising Peltier duty cycle should trigger a service warning.
- **Lifting.** About 6.2 kg when loaded; carry with the strap across the body.

## Open questions after TRL 3

Open decisions and items to confirm are kept in the design decisions register, [CPD-DEC-001](06-design-decisions.md). In short:

- Decided by Amish on 2026-10-02: the design-for-construction changes (CPD-DDR-003) are accepted; R12 is relaxed to 5.75 kg for the prototype, to be settled by weighing at TRL 4; R8 is restated as 9 h for all the PCM.
- Does the lid gasket still seal with the tray landed on the can flange, and does the tray seat give about 0.5 K/W?
- Can the loop thermosiphon be made and charged reliably at this size with R-134a (decided 2026-10-02; charge set by the technician from the loop volume), and does a motorbike carrier stay within about 19° of tilt with the cooling head down? If not, the mechanical disconnect (choice 2b) is the fallback.
- Confirm the off-state conductance and real COP of the chosen module with the chosen heat sink, and the sink's resistance with the fan.
- Confirm the VIP supplier, panel sizes, aged conductivity and edge losses; joints and edges are about 45 % of the heat leak.
- Confirm the usable latent heat of the PCM between 2 and 8 °C, its supercooling and its behavior over many cycles.
- Where to place the payload probe so that it represents the warmest pen, not the average; the build places it across the top layer at the cooling end.
- Validate trip profiles, loads, alarm behavior and price with users through a partner: an immunization program, decided on 2026-10-02; first candidate to approach, PATH, or a national immunization program's outreach team reached through it. Nothing is agreed yet.

Drawings and media: [prototype build plan CPD-BLD-001](05-build-plan.md), [general arrangement CPD-DWG-001](../cad/drawings/CPD-DWG-001.pdf), [concept blueprint sheet](../media/concept-blueprint.pdf), [interactive 3D model](../media/viewer.html).

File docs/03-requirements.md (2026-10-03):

---
doc_id: CPD-REQ-001
title: ColdPod requirements
project: ColdPod
doc_type: Requirements
version: "0.9"
status: Draft
date: '2026-10-02'
author: Amish Chadha
license: CERN-OHL-S-2.0
revisions:
- version: "0.1"
  date: '2026-09-24'
  author: Amish Chadha
  change: Initial scaffold
- version: "0.2"
  date: '2026-09-25'
  author: Amish Chadha
  change: First measurable requirements for TRL 2, with status against the concept estimates
- version: "0.3"
  date: '2026-09-25'
  author: Amish Chadha
  change: Record Amish's decisions (CPD-DDR-001); R6 redefined to 16 h, R12 relaxed to 5.5 kg, R15 set to $300; status from CPD-CAL-001
- version: "0.4"
  date: '2026-09-25'
  author: Amish Chadha
  change: Recommendations accepted by Amish (DDR-002). R2 and R7 targets restated for the liner cut-out and buck-boost driver; status from CPD-CAL-001 v0.2
- version: "0.5"
  date: '2026-09-26'
  author: Amish Chadha
  change: Budget top-up approved by Amish; R15 target $310, status met against CPD-CAL-001 v0.3
- version: "0.6"
  date: '2026-10-01'
  author: Amish Chadha
  change: Status values from CPD-CAL-001 v0.4 for the constructable design (CPD-DDR-003, Draft); no target changed
- version: "0.7"
  date: '2026-10-01'
  author: Amish Chadha
  change: Budget treated as a value-engineering target
- version: "0.8"
  date: '2026-10-02'
  author: Amish Chadha
  change: "Decisions of 2026-10-02: R8 restated as 9 h, R12 relaxed to 5.75 kg for the prototype, R14 removal method for the prototype; R8 and R12 now met on paper"
- version: "0.9"
  date: '2026-10-02'
  author: Amish Chadha
  change: "Status against CPD-CAL-001 v0.7: battery shipping switch and R-134a charge added; R12 5.74 kg (0.01 kg margin); R15 $313, $3 over the value-engineering target"
---

# ColdPod requirements

These are the requirements for the concept, checked by calculation at TRL 3 in CPD-CAL-001 v0.7 against the constructable design of CPD-DDR-003, which Amish accepted on 2026-10-02. Amish decided the TRL 2 review items on 2026-09-25 (CPD-DDR-001): R6 is redefined from 24 h to 16 h at 43 °C (D5), R12 is relaxed from 5.0 kg to 5.5 kg (D6), R15 follows the $300 value-engineering target of D10 and the R10 alarm defaults are adopted (D9). He then accepted the TRL 3 recommendations (CPD-DDR-002): R2 now names the two hardware cut-outs in series and R7 names the buck-boost driver that serves the full 10 to 15 V vehicle range; no target was relaxed. The target is now $310 (CPD-DDR-002 N3), a hypothetical control target and not a limit, and R15 follows it. No target changed in v0.6; the values follow the constructable design. Against CPD-CAL-001 v0.4, ten requirements were met, three at risk, two **not met** by small margins (R8 and R12) and two not verifiable at TRL 3 (R10 and R16). On 2026-10-02 Amish relaxed R12 to 5.75 kg for the prototype and restated R8 as 9 h (CPD-DEC-001), so twelve were met on paper; after the battery shipping switch was added (BOM line 18, $5) the cost is $313 and R15 is $3 over its target, so eleven are met, three at risk, one not met (R15) and two not verifiable; R14's removal method was decided for the prototype. Before DDR-002 the count was seven met, five at risk and three not met (R2, R8, R12).

Table 1. Requirements.

| ID | Requirement | Target | Verification (TRL 3 or later) | Status at TRL 3 (CPD-CAL-001) |
| --- | --- | --- | --- | --- |
| R1 | Keep the payload in the safe range | 2 to 8 °C at a buffered probe anywhere in the payload space; control setpoint 5 °C | Heat-transfer calculation; later lab test in a climate chamber | Met on paper: liner held at 2 to 5 °C; the lid pack stays frozen near 2.8 °C on its cold plate in powered hold at 43 °C (was at risk) |
| R2 | Never freeze the payload | No payload-contact surface below 1 °C in normal operation or with a stuck-on Peltier driver; two hardware cut-outs in series in the Peltier supply, on the cold block (−5 °C) and on the liner (3 °C), independent of firmware (CPD-DDR-002) | Calculation of the cold path; fault analysis | Met on paper: with a stuck-on driver the liner settles near 2.0 °C after the liner cut-out opens (was not met, about −4 °C) |
| R3 | Carry a useful load | 1.0 L or more of usable payload; holds 20 or more insulin pens up to 170 mm long | Massing model | Met: 1.37 L, 24 pens, up to 172 mm |
| R4 | Hold with no power at all | 12 h or more at a constant +43 °C, starting with the PCM frozen | Heat-leak and PCM calculation | At risk: 13.3 h; 10.2 h with 30 % more heat leak |
| R5 | Hold off-grid on a full charge | 24 h or more at a constant +32 °C on the internal battery, then the PCM | Energy budget | At risk: 27.3 h; 21.4 h with 30 % more heat leak |
| R6 | Hold off-grid on a full charge in extreme heat | 16 h or more at a constant +43 °C on the internal battery, then the PCM; longer hot trips run from external power under R7 (redefined from 24 h, CPD-DDR-001 D5) | Energy budget | At risk: 16.7 h; 12.6 h with 30 % more heat leak |
| R7 | Hold indefinitely on external power | Keeps 2 to 8 °C up to +43 °C from 12 V DC (10 to 15 V, through a buck-boost Peltier driver, CPD-DDR-002) or USB-C PD (20 V, 45 W or more) | Peltier and heat sink calculation | Met on paper: 18.8 W input, well inside 45 W; the buck-boost stage covers a 10 V input; the lid pack stays frozen (was at risk) |
| R8 | Recharge the cold quickly | Refreeze a fully melted PCM in 9 h or less at 25 °C ambient, box empty, while charging the battery (restated from 8 h, CPD-DEC-001, 2026-10-02; still an overnight refreeze) | PCM and Peltier calculation | Met: 8.0 h (8.03 h) for all the PCM (jacket 6.8 h, lid pack 8.0 h); 8.4 h before the constructable design, which holds slightly less PCM |
| R9 | Record the temperature | Payload probe accuracy ±0.5 °C; log every 1 min; 60 days or more on board; export as CSV over Bluetooth Low Energy or USB | Datasheet and storage calculation; later calibration | Met: 1.38 MB of 2.10 MB; accuracy by sensor selection |
| R10 | Raise alarms early | Local sound, light and display alarm, plus a phone notification when paired: warn after 10 min outside 2 to 8 °C; alarm at once at 0 °C or lower on the payload probe; early freeze warning at 1 °C on the liner probe; low battery, sensor fault and lid open for more than 2 min (defaults decided, CPD-DDR-001 D9; adjustable per product) | Design review of firmware sketch | Not verifiable at TRL 3: design intent only, no firmware sketch |
| R11 | Keep logging when the cooling stops | Logger runs 14 days or more after the Peltier is shut off for low battery | Power budget | Met: about 96 days |
| R12 | Be light enough to carry all day | 5.75 kg (12.7 lb) or less empty for the prototype (relaxed from 5.0 kg, CPD-DDR-001 D6, and from 5.5 kg, CPD-DDR-003 A2, 2026-10-02) | Mass estimate, weighing at TRL 4 | Met on paper: 5.74 kg, 0.01 kg margin (0.05 kg before the battery shipping switch and the R-134a charge were added) (5.53 kg before the fixings and parts added to make the design buildable, CPD-DDR-003); no base bumper until the prototype is weighed |
| R13 | Be compact | Fits in 400 x 250 x 250 mm including handle | Massing model | Met: 366 x 220 x 207 mm |
| R14 | Travel by air | Battery 100 Wh or less, removable or with a shipping switch | Battery specification | Met for the prototype: 76.8 Wh; the pack comes out with the battery bay (four screws), counted as removable for the prototype (CPD-DDR-003 A3, 2026-10-02). Before any field or air travel use: a shipping switch and the carrier's lithium battery rules |
| R15 | Be affordable and buildable | Estimated parts cost within the $310 value-engineering target (hypothetical control target, CPD-DDR-002 N3); no custom PCB for the first build | Priced BOM | Over the value-engineering target by $3: $313 against $310, after the $5 battery shipping switch (BOM line 18) added on 2026-10-02 |
| R16 | Survive field use | Splash resistant (IP54 target for electronics bays); survives a 0.5 m drop onto a hard floor while loaded | Design review; later test | Not verifiable at TRL 3 |
| R17 | Be clearly labelled as a prototype | "Research prototype, not a medical device" on the box, the display start screen and every exported log | Design review | Met by design |

## Assumptions

- Ambient cases follow the WHO PQS test point of +43 °C for the hot zone ([WHO PQS E004/VC01](https://extranet.who.int/prequal/key-resources/documents/pqs-independent-type-testing-protocol-e004vc01-vp2-vaccine-carrier)), +32 °C for a typical hot day and 25 °C for a clinic.
- The 2 to 8 °C window and the no-freezing rule come from insulin and vaccine storage guidance ([US FDA](https://www.fda.gov/drugs/emergency-preparedness-drugs/information-regarding-insulin-storage-and-switching-between-products-emergency); [CDC Pink Book, chapter 5](https://www.cdc.gov/pinkbook/hcp/table-of-contents/chapter-5-vaccine-storage-and-handling.html)).
- Logging and alarm targets are stricter than a WHO 30-day recorder (−0.5 °C for 60 min, +8 °C for 10 h; [TechNet-21](https://www.technet-21.org/en/temperature-monitoring/finding-the-right-solution/finding-the-right-solution-30dtr)) because a carrier in transit can move out of range much faster than a refrigerator.
- R6 matches the WHO long-range carrier cold life only loosely: a WHO carrier is tested passive for 30 h at 43 °C. ColdPod does not claim WHO equivalence.
- The alarm thresholds in R10 were decided by Amish on 2026-09-25 (CPD-DDR-001 D9) and will be adjustable per product.
- Hold-time status uses a ±30 % band on the heat leak: met if the target holds at +30 %, at risk if it holds only at the nominal estimate (CPD-CAL-001).
- R15 counts ColdPod parts only; the payload is not costed.

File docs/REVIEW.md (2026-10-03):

# Review note: ColdPod

## Session 2026-09-26: sources strengthened

Amish asked on 2026-09-26 to "Fix the weaker sources" and approved the budget top-ups ("I am ok with the budget top ups"). Every link kept or added in the README sections Concept rationale, Burning platform, Where it could be used and What sparked the idea was fetched and checked against its claim.

| Where | Old source | New source |
| --- | --- | --- |
| Country row: Latin America, including the Amazon basin | None (claim of multi-day river outreach and distant freezers, uncited) | PAHO stories on river vaccination in Putumayo, Colombia (2024) and boat or plane access in Panama; the row now states only what they report |
| Country row: Sub-Saharan Africa | WHO PQS E004/VC01-VP2 test protocol page (could not be fetched for checking) | WHO PQS E004/VC01.2 vaccine carrier performance specification (cold life at a constant +43 °C) |
| Country row: United States | US FDA (kept; wording narrowed from "hurricanes, wildfires and power cuts" to natural disasters and other emergencies, which is what the page says) | Same |
| Burning platform: Hanson et al., 2017 | Kept; the wording "33 % of storage studies" was corrected to the review's pooled estimate of storage and shipments | Same |

What sparked the idea (vaccine vial monitor, PATH and an Ethiopian Federal Ministry of Health training module on OpenLearn Create) was checked and kept. docs/01-problem.md still uses the "storage studies" wording and the VC01-VP2 link, which are not weak sources and were left for a later pass.

**Budget:** `budget_usd` raised from 300 to 310 (CPD-DDR-002 N3, decided by Amish, 2026-09-26). `sizing.py` now reads the budget from a `BUDGET_USD` constant and was re-run: BOM $303 against $310, R15 met. Counts: 10 met, 3 at risk, 2 not met (R8, R12), 2 not verifiable. Controlled documents: CPD-CAL-001 v0.3, CPD-REQ-001 v0.5, CPD-PRC-001 v0.5, CPD-PRB-001 v0.5, CPD-DDR-002 v0.2; README budget figures updated.

## Session 2026-09-25: /populate to a strong TRL 2 (overnight batch run)

### What was done

- `docs/01-problem.md` (CPD-PRB-001 v0.2): the problem (heat and freeze damage, fixed cold life of passive carriers, separate monitoring, closed commercial products), users and context, constraints, out of scope and open questions, with sources linked inline.
- `docs/03-requirements.md` (CPD-REQ-001 v0.2): 17 measurable requirements (R1 to R17) with targets, planned verification and status against the concept estimates.
- `docs/02-concept.md` (CPD-PRC-001 v0.2): how it works, components table numbered to the BOM and exploded view, first-order numbers with stated assumptions, nine design choices with options and recommendations, safety section, open questions.
- `cad/src/concept_media.py`: massing model (shell, lid, handle, VIPs, PCM packs, liner and rack with insulin pens, thermosiphon, Peltier module, heat sink and fan, end housings, LiFePO4 pack, power board, logger, sensors, display) with a table top and phone for scale.
- `media/`: `hero.png`, `concept-blueprint.png`, `.pdf` and `.svg`, `cutaway.png`, `exploded.png` with BOM callouts, `flow.png` (heat flow, all values marked as estimates), `model.glb` and `viewer.html`.
- `bom/bom.csv`: 16 lines with indicative prices, numbered to match the exploded view; `bom/bom-notes.md` updated.
- `README.md`: hero image and links line added before "## Problem"; problem, concept, key components and safety updated.
- `docs/pdf/`: branded PDFs of the three controlled documents.
- `project.yaml`: unchanged. The pitch and problem lines still match the concept.
- `cad/src/model.py` (the scaffold placeholder) is unchanged; the parametric model is TRL 3 work.

### Key results (estimates, to be checked at TRL 3)

| Quantity | Estimate | Requirement |
| --- | --- | --- |
| Payload | about 1.2 L, about 24 insulin pens | R3 met |
| Overall heat leak | about 0.11 W/K (±30 %) | Drives every hold time |
| Passive hold, PCM only, 43 °C | about 12.7 h | R4 met, thin margin |
| Off-grid hold (battery then PCM), 32 °C | about 26 h | R5 met, thin margin |
| Off-grid hold (battery then PCM), 43 °C | about 16 h | R6 **not met** (24 h) |
| Power to hold on external supply, 43 °C | about 17 W | R7 met on estimate |
| PCM refreeze, 25 °C, empty | about 6 h | R8 met |
| Mass, empty | about 5.2 kg | R12 **not met** (5.0 kg) |
| Size | about 370 x 215 x 205 mm | R13 met |
| Battery | 76.8 Wh LiFePO4 | R14 met |
| Parts cost | about $280 | R15 **not met** ($250) |

Requirements not met: R6 (about 16 h against 24 h at 43 °C off-grid), R12 (about 5.2 kg against 5.0 kg) and R15 (about $280 against $250). R4 and R5 are met with thin margins that depend on the VIP heat-leak estimate. R16 (splash and drop) is unverified.

### Proposed, awaiting Amish

1. **PCM:** 5 °C organic PCM (recommended) rather than water ice or a 3 °C PCM, to prevent freezing.
2. **Cold path:** gravity thermosiphon as a one-way thermal link (recommended), with a mechanical disconnect as fallback, rather than bolting the Peltier to the liner.
3. **Evaporator position:** on the outer face of the PCM, not on the liner (recommended).
4. **Battery:** LiFePO4 4S1P, 76.8 Wh (recommended; airline-friendly), or 4S2P, 153.6 Wh (about $30 more, 0.6 kg heavier, about 20 h at 43 °C).
5. **R6 shortfall:** accept about 16 h at 43 °C and rely on vehicle or solar power for long hot trips (recommended); or a larger battery (about 20 h); or thicker VIPs and more PCM (reaches 24 h, but about 400 mm long and over 6 kg).
6. **R12 shortfall (mass):** relax the target to 5.5 kg (recommended, since the PCM and VIPs set most of the mass), or cut about 0.2 kg with thinner shell walls and a lighter liner.
7. **Insulation:** VIPs (recommended), with a polyurethane foam variant documented as a low-cost option (saves about $45, hold at 43 °C drops to about 7 h).
8. **Connectivity:** local alarms plus Bluetooth Low Energy only in the first build (recommended); cellular or LoRa later.
9. **Alarm defaults:** warn after 10 min outside 2 to 8 °C; alarm at once at 0 °C or lower on the payload probe; early freeze warning at 1 °C on the liner probe.
10. **Budget:** parts cost about $280 against `budget_usd: 250`. Options: raise to $300 (recommended); keep $250 with foam insulation; keep $250 with a 0.8 L liner. `project.yaml` is unchanged.
11. **First user and partner:** outreach vaccinators first (recommended; sets the 43 °C case), or travellers with insulin; partner to be chosen (immunization program, diabetes association or humanitarian logistics group).

The SwapCell 48 V pack is not proposed: at about 468 Wh and 2.8 kg it is far larger than this design needs.

### Safety concerns

- Not a medical device and not WHO-prequalified; every document, the README and the proposed box labelling say so, and must keep saying so.
- A stuck-on Peltier driver could freeze the payload. The concept relies on the 5 °C PCM between the cold path and the liner, a hardware cold-block cut-out and liner and payload alarms. This needs a fault analysis at TRL 3.
- LiFePO4 battery (76.8 Wh) in a hot environment: BMS, fuse, charge blocked outside 0 to 45 °C, separate vented bay.
- Paraffin PCM is combustible and can soften some plastics; sealed HDPE pouches, kept away from the battery bay.
- Heat sink may reach about 55 to 65 °C at 43 °C ambient; enclosed, with a guarded fan.
- A punctured VIP loses its insulation invisibly; the design proposes a service warning from rising Peltier duty.

### Recommended next step

Review this note and the media. If approved, run `/advance-trl3` to calculate the heat leak with real VIP data, check the thermosiphon at tilt and the Peltier's off-state conductance, run a freeze-fault analysis, and produce the parametric model and drawing sheet. Settle R6, R12, R15 and the budget first, since they may change the box size.

## Session 2026-09-25: TRL 3

Amish's instruction for this session (2026-09-25): "proceed with all of your recommendations across all batches. Make sure we don't proceed to TRL 4 on any of them." ColdPod now claims TRL 3 (proof of concept on paper). TRL 4 is on hold by Amish's instruction.

### What was done

- `docs/decisions/0001-trl2-review-decisions.md` (CPD-DDR-001 v0.1): the eleven TRL 2 review items with a recommendation recorded as decided by Amish, 2026-09-25 (D1 to D11), and the items that stay open.
- `docs/04-calcs/01-sizing.md` (CPD-CAL-001 v0.1) and `docs/04-calcs/sizing.py`: first-principles sizing with stated assumptions: payload and size; heat leak by Langmuir shape factors with explicit VIP joint, foam strip, pipe and wire paths; PCM energy; passive hold; a Peltier model for three module classes with cold and hot paths; powered hold and input power; battery-then-PCM hold with a ±30 % heat-leak band; a time-stepped refreeze model; thermosiphon diode ratio and tilt limits; a stuck-on driver fault; logger storage and reserve; mass from model volumes; BOM total; foam variant; options for review. The script imports the model's `PARAMS` and prints every number the note quotes, tagged [A1] to [P2].
- `cad/src/model.py`: parametric build123d model (shell, lid, handle, VIP set with foam strip, PCM jacket and lid pack, liner and rack with 24 pens, evaporator can with a loop thermosiphon and cold block, Peltier, heat sink and fan, end housings, cells, boards, sensors, display), exporting `cad/step/coldpod-assembly.step`, `shell.step`, `lid.step`, `vip-set.step`, `liner-rack.step`, `evaporator-thermosiphon.step`, `cooling-head.step`, `end-housings.step` and matching STL files in `cad/stl/`.
- `cad/src/sheets.py` and `cad/drawings/CPD-DWG-001.svg`, `.pdf`, `.png`: general arrangement at Rev P1, scale 1:5, with overall dimensions drawn from the model and a main-dimensions box. The sheet carries "CONCEPT, NOT FOR FABRICATION" and "PRELIMINARY, NOT FOR FABRICATION". The concept sheet stays CPD-DWG-010, so DWG-001 was the next free number.
- `bom/bom.csv` and `bom/bom-notes.md`: all 16 lines priced with a supplier type; total $295 against the new $300 budget.
- `cad/src/concept_media.py` now builds the media from `model.py` and takes its figures from the calc script; all media in `media/` were regenerated and checked by eye (a tangent tube that made the PCM solid invalid, and so missing from the cutaway, was fixed); temporary `media/_views*` folders were deleted.
- CPD-PRB-001, CPD-PRC-001 and CPD-REQ-001 revised to v0.3 (decisions recorded, numbers replaced by CPD-CAL-001, status column from the calc); `README.md` updated to TRL 3 with links; `project.yaml` set to `trl: 3`, `trl_target: 3`, `budget_usd: 300`, with the evidence files listed. PDFs are in `docs/pdf/`.

### Requirements (CPD-CAL-001, Table 9)

7 met, 5 at risk, 3 not met, 2 not verifiable at TRL 3. Hold times count as met only if they survive 30 % more heat leak than estimated.

| ID | Status | Value against target |
| --- | --- | --- |
| R2 | **Not met** | Normal operation met; with a stuck-on driver the liner can reach about −4 °C, because the only hardware cut-out is on the cold block at −5 °C |
| R8 | **Not met** | The jacket refreezes in 5.5 h (8 h target), but the lid PCM pack (0.28 kg) has no cold path to the evaporator |
| R12 | **Not met** | 5.60 kg against the relaxed 5.5 kg; the evaporator can adds 0.25 kg |
| R1 | At risk | Liner held at 2 to 5 °C, but in long powered holds at 43 °C the lid pack melts (after about 21 h) and settles near 13.8 °C above the top layer of pens |
| R4 | At risk | 13.0 h at 43 °C with no power; 10.0 h at +30 % leak (12 h target) |
| R5 | At risk | 26.5 h at 32 °C off-grid; 20.1 h at +30 % leak (24 h target) |
| R6 | At risk | 16.5 h at 43 °C off-grid; 12.4 h at +30 % leak (16 h target, redefined by D5) |
| R7 | At risk | 18.4 W input at 43 °C, inside the 45 W PD budget; lid pack melts after about 21 h; a 10 V vehicle input leaves little driver headroom for the 9.5 V module |
| R10 | Not verifiable at TRL 3 | Alarm logic is design intent only; no firmware sketch was written |
| R16 | Not verifiable at TRL 3 | Splash and drop need a test |
| R3, R9, R11, R13, R14, R15, R17 | Met | 1.36 L and 24 pens; 1.38 MB of 2.10 MB; about 96 days of logger reserve; 368 x 214 x 207 mm; 76.8 Wh; $295; labelling by design |

Other key numbers: overall conductance 0.091 W/K (0.11 at TRL 2), of which joints and edges are about 45 %; PCM 0.972 kg and 175 kJ (1.06 kg and 191 kJ at TRL 2, because the evaporator can and tubes take space); input to hold 4.2, 7.5 and 18.4 W at 25, 32 and 43 °C; the TEC1-12706 named at TRL 2 cannot hold at 43 °C at all (its off-state conduction is too high), so the TEC1-12703 class is used; on/off PWM would cost 61 % more power than smooth DC; thermosiphon forward to reverse ratio about 430, full function to 18° of tilt with the cooling head down; heat sink base about 53 °C at 43 °C; foam variant 7.4 h passive at 43 °C. Every TRL 2 number in the docs was checked against the script and corrected where it differed (CPD-CAL-001, Table 8).

### Decisions recorded (CPD-DDR-001)

Decided by Amish, 2026-09-25, going with the recommendation: D1 5 °C organic PCM; D2 thermosiphon, mechanical disconnect as fallback; D3 evaporator on the outer face of the PCM; D4 76.8 Wh LiFePO4 4S1P; D5 accept about 16 h at 43 °C off-grid (R6 redefined to 16 h); D6 R12 relaxed to 5.5 kg; D7 VIPs, foam variant documented; D8 local alarms and Bluetooth Low Energy only; D9 alarm defaults; D10 `budget_usd` raised to $300 (set in `project.yaml`); D11 outreach vaccinators first. The pitch and problem lines were not asked to change and are unchanged. ColdPod does not use a SwapCell pack, so the SwapCell interface v0.3 items and the shared-pack pricing rule do not affect it.

### Proposed, awaiting Amish

Still open from TRL 2 (no recommendation was made):

1. Co-design partner: an immunization program, a diabetes association or a humanitarian logistics group (O1). Portfolio rule: partners are picked per area later.

New from TRL 3:

2. **Lid pack cold path (R8, R1, R7).** Options: (a) a 1.5 mm aluminium plate under the lid pack that seats on the evaporator can rim when the lid closes (about $5 and 0.12 kg; lid pack refreezes in about 2.3 h); (b) drop the lid pack and use a 20 mm jacket (1.010 kg of PCM, all actively frozen; body 10 mm longer and wider, 10 mm lower; the top of the cavity then sees the lid VIP directly); (c) keep the design and condition the lid pack in a refrigerator. Recommendation: (a), and check the gasket still seals with the plate in place.
3. **Freeze fault (R2).** Add a second hardware cut-out on the liner, opening at 3 °C, in series with the cold-block cut-out (about $3). The liner then settles near 2.0 °C after a stuck-on fault (1.2 °C for a 2 °C setting). Recommendation: adopt.
4. **Mass (R12).** Options: (a) thinner printed parts (3 mm shell, 5 mm lid cap, 2 mm housings), about 5.39 kg, or about 5.51 kg with the lid cold plate; (b) relax R12 again to 5.75 kg; (c) keep and accept the miss. Recommendation: (a), and confirm by weighing after TRL 3.
5. **Evaporator can and loop thermosiphon.** The decided D2 and D3 are sized as a 1.0 mm aluminium can around the jacket fed by an 8 mm copper loop; this is in the model and BOM line 7 ($28). Charging the loop needs refrigeration tools. Recommendation: confirm; keep the mechanical disconnect (D2 fallback) ready if a maker cannot charge the loop.
6. **Peltier class and drive.** TEC1-12703 class module with a buck driver and LC filter (smooth DC), and a heat sink of 0.50 K/W or better with the fan. In the model and BOM. Recommendation: confirm.
7. **Vehicle input headroom (R7).** At 10 V input the 9.5 V module drive leaves little margin. Options: (a) a buck-boost driver; (b) redefine the 12 V input range as 11 to 15 V. Recommendation: (a), if it fits the power board cost.
8. **Budget margin.** The BOM is $5 under the $300 budget, and the VIP set ($60) and thermosiphon ($28) are estimates. Recommendation: get a VIP quote before any purchase decision; `budget_usd` stays at $300.

### Safety concerns

- Not a medical device and not WHO-prequalified; every document, the README and the proposed box labelling say so.
- Freeze fault: with the present single cut-out on the cold block, a stuck-on driver can freeze the liner (R2 not met). Item 3 above fixes it on paper.
- LiFePO4 battery (76.8 Wh): BMS, fuse, charging blocked outside 0 to 45 °C, separate vented bay away from the heat sink.
- Paraffin PCM is combustible and can soften some plastics; sealed HDPE pouches, kept away from the battery bay.
- Heat sink base about 53 °C at 43 °C ambient; enclosed with a guarded fan.
- A punctured VIP loses its insulation invisibly; a rising Peltier duty should raise a service warning.
- The loop thermosiphon holds a working fluid under pressure; charging needs refrigeration tools and practice.
- Loaded mass about 6.3 kg; carry with the strap across the body.

### Other notes

- No existing TRL 4 material was found (`build-log/` holds only its README; `electronics/` and `firmware/` are empty). None was created. STANDARDS section 9 asks for a TRL change to be recorded in the build log; no build-log entry was written this session, since the brief did not name one.
- The TRL 2 review listed no unchecked citations, so no web verification was run. The sources in CPD-PRB-001 and CPD-REQ-001 are unchanged. BOM prices are indicative estimates by supplier type, not quotes.
- `.claude/commands/advance-trl3.md` names the drawing DWG-001; that number was free (the concept sheet is CPD-DWG-010), so the general arrangement is CPD-DWG-001.

### Recommended next step

Stay at TRL 3. TRL 4 is on hold by Amish's instruction. Decide items 2 to 8 above, starting with the lid pack cold path and the liner cut-out (they close R8 and R2), then revise the model, CPD-CAL-001 and the BOM on paper, and request quotes for the VIP set and the thermosiphon.

For reference only, TRL 4 would need: a lab test report (TST, `environment: lab`) on a built case or key subassemblies (heat leak by a steady-state heater test, passive and powered hold times in a climate chamber at 25, 32 and 43 °C, refreeze time, thermosiphon forward and reverse conductance and tilt limit, stuck-on driver fault test, alarm behavior, mass), build-log entries, and the purchasing and build work that goes with them. None of this has been started.

## Session 2026-09-25: recommendations accepted

Amish wrote on 2026-09-25: "i accept all your recommendations, go with them across all repos." Every open item with a recommendation is now **decided by Amish, 2026-09-25: go with recommendation**, recorded item by item in `docs/decisions/0002-recommendations-accepted.md` (CPD-DDR-002 v0.1). TRL 4 remains on hold; `trl` and `trl_target` stay at 3.

### Decisions applied and what changed

Items 2 to 8 of the TRL 3 list "Proposed, awaiting Amish" above (D1 to D11 in CPD-DDR-001 were already decided):

| Item | Decision | Change (before to after) |
| --- | --- | --- |
| 2 Lid pack cold path | (a) 1.5 mm aluminium lid cold plate seated on the can rim | Added to model, BOM line 2 ($8 to $12), drawing, media. Lid pack in powered hold at 43 °C: melted after about 21 h and settled near 13.8 °C, to held frozen near 2.8 °C. Passive hold at 43 °C: 13.0 to 14.0 h (jacket and lid pack now pooled). Off-grid: 26.5 to 28.4 h at 32 °C, 16.5 to 17.5 h at 43 °C. Refreeze: jacket only 5.5 h (lid pack could not be refrozen) to all PCM 8.4 h |
| 3 Freeze fault | Liner cut-out at 3 °C in series with the cold-block cut-out | Added to model and BOM line 14 ($10 to $13). Liner after a stuck-on fault: about −4 °C to about 2.0 °C |
| 4 Mass | (a) Shell 4 to 3 mm, lid cap 8 to 5 mm, housings 3 to 2 mm | Model and BOM lines 1 ($18 to $17) and 10 ($8 to $6). Empty mass 5.60 to 5.53 kg (with the plate). Weighing is TRL 4, on hold |
| 5 Evaporator can and loop | Confirmed as sized; mechanical disconnect kept as fallback | Wording only. Loop charging is build work, on hold |
| 6 Peltier class and drive | Confirmed: TEC1-12703 class, smooth DC, 0.50 K/W sink | Wording only |
| 7 Vehicle input headroom | (a) Buck-boost Peltier driver | BOM line 12 ($22 to $26); R7 target text names it. Input at 43 °C 18.4 to 18.5 W (thinner shell, taller lid stack) |
| 8 Budget margin | `budget_usd` stays at $300; VIP quote before any purchase | `project.yaml` unchanged. The quote request goes with purchasing, TRL 4, on hold |

Budget: `budget_usd` unchanged at 300. BOM total $295 to $303. Overall size 368 x 214 x 207 mm to 366 x 212 x 207 mm. Drawing CPD-DWG-001 Rev P1 to P2. Controlled documents: CPD-DDR-001 v0.2, CPD-PRB-001 v0.4, CPD-PRC-001 v0.4, CPD-REQ-001 v0.4, CPD-CAL-001 v0.2, new CPD-DDR-002 v0.1. All media, STEP and STL files, the drawing and every PDF were regenerated (the footers now read designmolecule.com); superseded PDFs that showed the old domain were deleted. The README gained the Concept rationale, Burning platform, Where it could be used and What sparked the idea sections; the idea's origin is the vaccine vial monitor (1996), which records heat but not freezing.

### Requirement status (CPD-CAL-001 v0.2)

| ID | Status | Value against target |
| --- | --- | --- |
| R8 | **Not met** | 8.4 h for all the PCM against 8 h (jacket 6.9 h, lid pack 8.4 h); 30 W to the module only reaches 8.2 h |
| R12 | **Not met** | 5.53 kg against 5.5 kg |
| R15 | **Not met** | $303 against $300 |
| R4 | At risk | 14.0 h at 43 °C; 10.8 h at +30 % leak (12 h) |
| R5 | At risk | 28.4 h at 32 °C; 22.3 h at +30 % leak (24 h) |
| R6 | At risk | 17.5 h at 43 °C; 13.2 h at +30 % leak (16 h) |
| R10, R16 | Not verifiable at TRL 3 | Firmware sketch and tests needed |
| R1, R2, R3, R7, R9, R11, R13, R14, R17 | Met | R1 and R7 were at risk and R2 was not met before this session |

Counts: 9 met, 3 at risk, 3 not met, 2 not verifiable (before: 7, 5, 3, 2).

### Still awaiting Amish

1. Co-design partner (CPD-DDR-001 O1). No recommendation was made.
2. R8 refreeze, 8.4 h against 8 h (CPD-DDR-002 N1). Options: restate R8 as 9 h for all the PCM (suggested); accept the miss; a thinner lid pack.
3. R12 mass, 5.53 kg against 5.5 kg (N2). Options: keep the target and settle it by weighing when TRL 4 resumes (suggested); relax to 5.6 kg; lighter strap and handle.
4. R15 cost, $303 against $300 (N3). **Decided by Amish, 2026-09-26:** budget top-up to $310. `budget_usd` is now 310 and R15 is met (see Session 2026-09-26 below).

### Cross-repo actions

None. ColdPod shares no part or interface with another repo and no recommendation named one.

### TRL 4

Remains on hold by Amish's instruction. Decided but on hold: weighing the case, checking the gasket seal and plate seat on a built lid, charging the loop thermosiphon, VIP and thermosiphon quotes and any purchasing, and all climate chamber tests. No build, test, PCB or firmware work was done.

## Session 2026-09-26: product appearance model and photoreal renders

Amish chose ColdPod on 2026-09-26 for the first batch of product renders. This session added an appearance model for photoreal renders; the render images themselves (`media/render-hero.png`, `media/render-exploded.png`) are produced later by the portfolio render pipeline.

### What was done

- `cad/src/product_model.py` (new): `product_parts()` returns 53 named parts (28 shell, 22 internal, 3 accessory, no context) with colour, material class, BOM line, group and exploded-view offset, plus `TITLE` and `RENDER_VIEWS` (hero from the front right, exploded from the front right, and a detail view of the battery bay and logger display from the front left). It imports `PARAMS`, `levels()` and `build_parts()` from `model.py` and keeps every main dimension and interface: 261 x 196 mm tub, 169.5 mm lid top, 207 mm to the top of the handle, 60 mm cooling head and 45 mm bay at 160 mm wide, pipe pass-throughs, cold block, Peltier, sink, fan, cells and boards where `model.py` puts them.
- Appearance detail added: 12 mm plan radius and filleted edges on the tub, lid and end housings; a black EPDM gasket line under the lid; a rubber base bumper; two teal draw latches on the front; a round steel bail with a ribbed rubber grip on pivot bosses; rounded grille, intake and vent slots; housing screws; a raised lid wordmark, lid range marking and a front label plate; a lit e-paper display with an illustrative readout, a lit green status light and a red alarm light; USB-C and 12 V inlets; a vented ambient sensor cap; fan blades; the internal stack split for the exploded view (VIP body set and lid plug, PCM jacket and lid pack, liner and rack, evaporator can, copper loop and cold block); and the padded shoulder strap as a fabric accessory.
- `README.md`: the hero image now points to `media/render-hero.png`, and the links line starts with the exploded render.
- Matplotlib self-check previews were made outside the repo; nothing in `media/` was changed.

### Differences from model.py (each Proposed, awaiting Amish)

1. **Handle form.** `model.py` has square 16 x 8 mm arms from Z = 128 mm and a 16 mm top bar. The appearance model uses a 10 mm round steel bail with 22 mm bends, pivot eyes at Z = 136 mm on 24 mm bosses, and a 16 mm ribbed rubber grip; the grip top stays at 207 mm. Recommendation: adopt the round bail in `model.py` at the next model revision; it matches the bought folding handle in BOM line 3.
2. **Window over the heat sink.** The appearance model has an 83 x 88 mm smoked window in the top of the cooling head so the fins show; `model.py` has a solid top. Options: (a) keep it as render styling only; (b) adopt it, with a check that it cannot be touched hot and does not change the airflow; (c) replace it with more exhaust slots. Recommendation: (a) for now, because it adds a part and a hot-surface question for no thermal benefit.
3. **Inlet positions.** USB-C and 12 V inlets are drawn low on the +X face of the cooling head, next to the power board; `model.py` does not place them. Recommendation: adopt this position (short leads to the power board, away from the battery bay).
4. **Latch positions and no hinge.** The two BOM line 2 draw latches are drawn on the front at X = ±72 mm, and the lid lifts off. Options: one latch front and one back, or a rear hinge. Recommendation: two front latches with a lift-off lid, as drawn, since a lid tether is simpler than a hinge through the VIP.
5. **Second status light.** `model.py` has one alarm light beside the display; the appearance model adds a red light at the mirrored position, matching the red and green LEDs already in BOM line 15. Recommendation: adopt.
6. **Base bumper, labels and wordmark.** A 12 mm rubber bumper around the base, a front label plate and a raised lid wordmark are not in the BOM. Recommendation: keep the labels under BOM line 16 and decide the bumper when the shell is next revised (it adds grams against R12, which is already 0.03 kg over).
7. **Shoulder strap anchors.** The strap is shown loose as an accessory; neither model places its anchor points. Recommendation: decide the anchors (handle pivots or end-housing lugs) with the next model revision.

### Scope

This is an appearance model only: no tolerances, no fabrication detail, and nothing past TRL 3. `trl` stays 3 in `project.yaml`, and TRL 4 remains on hold. `model.py`, the BOM and the controlled documents were not changed.

## Session 2026-09-27: kit 1.5.0 and image quality

- Kit 1.5.0 synced: STANDARDS v1.5 (sections 12 to 15: product renders, storefront images and image quality, public release, authorship and signing), `.kit/cards.py`, `.kit/image_qc.py`, `.kit/release_gate.py`, issue templates, and the `/render-product` and `/release` commands. `CLAUDE.md` now matches `.kit/CLAUDE.md`.
- Every `media/render-*.png` recaptioned from its original render with the new layout: the title, concept label and repository sit in a band above the render and the view note in a band below it, each line wrapped to the image width, so no text overlaps other text or the render or runs off the image. `media/card.png` and `media/social-preview.png` regenerated with the same rules.
- `python .kit/image_qc.py` and `python .kit/release_gate.py` pass. trl stays 3.

## Session 2026-10-01: kit 1.7.0, design made constructable, prototype build plan

Amish approved the build plan format on 2026-09-30 and asked for it across all repos, with outstanding decisions kept out of the plan and in a separate register. Under his 2026-09-30 instruction ("If you are realising that the design cannot be built as per concept - fix the design assumptions to match and be physically feasible as you draw the illustrations"), the design was made constructable. Every change is recorded in CPD-DDR-003 (Draft, open for his review). TRL stays 3; nothing was built or tested.

### What was done

- Kit 1.7.0 installed (`.kit/`, `.claude/commands/`); `CLAUDE.md` matches `.kit/CLAUDE.md`.
- `cad/src/model.py`: rebuilt as 49 separate components (`build_components()`), grouped back into the 17 concept groups for the media, product model and calculations; 63 constructability checks (`python cad/src/model.py --check`), all pass. STEP and STL regenerated.
- `docs/decisions/0003-design-for-construction.md` (CPD-DDR-003 v0.1, Draft).
- `docs/05-build-plan.md` (CPD-BLD-001 v0.1): 17 component subsections, 20 assembly steps, first checks, nine safety stops.
- `docs/06-design-decisions.md` (CPD-DEC-001 v0.1): seven open decisions, seven items to confirm when parts are bought, four decisions made.
- `cad/src/build_plan_media.py`: overview, VIP panel picture, 15 making sketches (CPD-DWG-101 to 115), 9 joint close-ups, 20 step pictures and the wiring diagram.
- CPD-CAL-001 v0.4 (PCM volumes now measured on the model), CPD-REQ-001 v0.6, CPD-PRC-001 v0.6, `bom/bom.csv` (lines 1, 2, 4 to 7, 14, 16 changed; line 17 added), `bom/bom-notes.md`, CPD-DWG-001 Rev P4, concept media, README (links line and "Building the prototype"), `project.yaml` (`design_state: constructable`, both new documents in `trl_evidence`).

### Design changes made for construction (CPD-DDR-003)

1. Payload probe: a 10 x 40 mm vial across the top layer of pens; the old probe overlapped the pens by 2.35 cm³.
2. Loop: the evaporator ring bonded into the bottom inside corner of the can (it floated in the PCM); 25 mm corner bends.
3. Risers: 17.5 mm bends lying in the foam strip; can and shell slots open at the rim; three printed slot fillers; foam strip 20 to 28 mm tall.
4. Cold block: two tube sockets, a drilled condensing passage and a charge stub, brazed with aluminium-to-copper rod; the loop is charged on the bench as one sealed unit.
5. Peltier stack: a printed block frame screwed to two printed towers on the shell; two M3 clamp screws through the sink into the block; fan and guard on the sink.
6. End housings: printed pads with M3 inserts on both shell ends, ears on both housings.
7. Handle and latches: printed pads with M5 and M3 inserts; handle arms 4 mm further out (width 212 to 220 mm).
8. Liner and lid: 5 mm inward rim flange on the can; liner on four printed feet and a printed collar; the lid cold plate folded into a tray bonded to the lid VIP plug, landing on the flange.
9. VIPs: seven panels with order sizes; the lid plug 0.5 mm under the opening.
10. Electronics: power board and logger on standoffs, a printed cell cradle, the display under a window.
11. Condensate: a drip tray on the block frame and a drain tube through the head floor.
12. Cables and inlets: grommets and a cable slot at the cooling end, a printed cable duct cover on the back face, 12 V and USB-C inlets low on the head's end wall, a reed lid switch in the head.

### Key results (CPD-CAL-001 v0.4)

PCM 0.972 to 0.935 kg. Passive hold at 43 °C 14.0 to 13.3 h (R4 at risk); off-grid 27.3 h at 32 °C (R5 at risk) and 16.7 h at 43 °C (R6 at risk). Refreeze of all the PCM 8.4 to 8.0 h (8.03 h, R8 **not met** by a few minutes). Mass 5.53 to 5.70 kg (R12 **not met** by 0.20 kg). Size 366 x 220 x 207 mm (R13 met). BOM $303 to $308 against the $310 value-engineering target (R15 within the target). Counts unchanged: 10 met, 3 at risk, 2 not met, 2 not verifiable.

### Proposed, awaiting Amish

All in the design decisions register (CPD-DEC-001): accept CPD-DDR-003 (recommended); mass, now 0.20 kg over (recommend relaxing R12 to 5.75 kg); refreeze R8 (recommend restating as 9 h); battery removal for R14 (recommend counting the four-screw bay as removable for the prototype); the loop's working fluid (decide with the technician); the co-design partner; and the remaining appearance-model items.

### Safety concerns

The loop is a sealed refrigerant circuit: brazing and charging are for a qualified technician, before any plastic, VIP or PCM is near it (build plan S1, S2). No hot work once the paraffin is in (S8). A punctured VIP fails silently; the build plan bans tools near the panels (S3). The battery, first power and first charge stops (S4 to S7) carry over from the concept's safety section.

### Stale until regenerated on Amish's Mac

The photoreal renders (`media/render-hero.png`, `media/render-exploded.png`, `media/render-detail.png`), `media/card.png`, `media/social-preview.png` and the appearance model `cad/src/product_model.py` still show the concept: no pads, towers, slots or duct, a flat lid plate and the handle 4 mm closer to the shell.

### Recommended next step

Amish reviews CPD-DDR-003 and the register. TRL 4 (building to the plan) stays on hold until he asks for it.

## Session 2026-10-02: open decisions decided

Amish, 2026-10-02: "i approve your recommendations for all 555 open decisions." This approves the recommendation written for every open decision in the design decisions register (CPD-DEC-001). trl stays 3; nothing was built, bought or tested, and TRL 4 remains on hold.

### Decisions recorded (7)

| Register item | Decision |
| --- | --- |
| 1 | CPD-DDR-003 accepted: P1 to P12 and their knock-on changes, as made |
| 2 | R12 relaxed to 5.75 kg for the prototype; weighed at TRL 4; base bumper left off |
| 3 | R8 restated as 9 h for all the PCM at 25 °C |
| 4 | Battery bay on four screws counts as removable for the prototype; shipping switch and carrier rules before any field or air travel use |
| 5 | R-134a (non-flammable, A1) for the prototype loop, charge set by the technician; R-1234yf only for a product version |
| 6 | Partner: an immunization program; first candidate to approach, PATH or a national program's outreach team through it |
| 7 | Round bail in the model, solid heat sink, second status light adopted, labels and wordmark under BOM line 16, no bumper until weighed |

All 7 moved to Decisions made in CPD-DEC-001, dated 2026-10-02; the Open decisions section now reads "None."

### Documents changed

- `docs/06-design-decisions.md` (CPD-DEC-001 v0.3): items 1 to 7 moved to Decisions made; Open decisions reads "None"; the 2026-09-30 row now points to the acceptance
- `docs/decisions/0003-design-for-construction.md` (CPD-DDR-003 v0.3): status accepted (kept Draft); A1 to A4 marked accepted; requirement consequence added
- `docs/03-requirements.md` (CPD-REQ-001 v0.8): R8 restated as 9 h, R12 relaxed to 5.75 kg (both met on paper), R14 status states the prototype removal method and the travel rule; counts updated
- `docs/04-calcs/01-sizing.md` (CPD-CAL-001 v0.6): R8, R12 and R14 text and Table 9 against the restated targets; counts 12 met, 3 at risk, 2 not verifiable
- `docs/02-concept.md` (CPD-PRC-001 v0.8): summary and results table against the new targets; refrigerant and battery removal safety notes; first partner candidate
- `docs/01-problem.md` (CPD-PRB-001 v0.6): partner type and first candidate to approach
- `docs/05-build-plan.md` (CPD-BLD-001 v0.2): section 2 says CPD-DDR-003 is accepted; R-134a named for the loop and in safety stop S2
- `bom/bom-notes.md`: CPD-DDR-003 accepted; R-134a for item 7; labels and wordmark under item 16
- `README.md`: R8 and R12 against the new targets
- `docs/decisions/0001-trl2-review-decisions.md` (CPD-DDR-001 v0.3): item O1 ("Proposed, awaiting Amish") recorded as decided
- `docs/decisions/0002-recommendations-accepted.md` (CPD-DDR-002 v0.3): items O1, N1 and N2 (awaiting Amish) recorded as decided
- PDFs regenerated with `python3 .kit/render.py`; superseded versions removed.

### Follow-up actions to carry approved decisions into the design

The model, BOM quantities and prices, calculations and pictures were not changed in this session. These actions carry the approved decisions into them:

1. Decision 2 and 3 (calculations): Re-run `docs/04-calcs/sizing.py` with R8 at 9 h and R12 at 5.75 kg so its R8, R12 lines, counts and `results.csv` match CPD-REQ-001 v0.8.
2. Decision 2 (test plan): Weigh the prototype at TRL 4 against 5.75 kg before any base bumper is added.
3. Decision 4 (model, BOM, build plan pictures): Before any field or air travel use, add the shipping switch to the battery bay: model, BOM line, wiring picture and build plan section; check the carrier's lithium battery rules.
4. Decision 5 (BOM): Name R-134a and its charge allowance in BOM line 7 (currently the charged loop without a named fluid) and price the charge with the technician.
5. Decision 6 (documents): Approach the first candidate partner (PATH, or a national immunization program's outreach team through it); nothing is agreed yet.
6. Decision 7 (model): Add the second (red) status light at the mirrored position beside the display in `cad/src/model.py`, matching the red and green LEDs of BOM line 1.
7. Decision 7 (pictures): Update `cad/src/product_model.py` and regenerate the photoreal renders, card and social preview on Amish's Mac: round bail, solid cooling head top (no window), second status light, labels and wordmark, no base bumper.

### Points found in the review

Raised when the recommendations were written (2026-10-01) and kept here so they are not lost:

- R14 is shown as 'Met: 76.8 Wh' in CPD-REQ-001 v0.6 while the battery removal question (CPD-DDR-003, A3; register item 4) is still open; the status should read 'met on paper, removal method awaiting Amish'.
- Item 3 options omit the power-split option in CPD-CAL-001 (G10): giving the module 30 W and the battery 7 W brings refreeze to 7.8 h, meeting R8, at the cost of an 11.5 h battery recharge.
- Item 6 lists a diabetes association and a humanitarian logistics group as equal options, but D11 already decided outreach vaccinators first; the options should be narrowed.
- Item 2's 5.75 kg limit leaves only 0.05 kg on estimated masses; if the bumper (item 7) were adopted it would likely use that margin up.

## Session 2026-10-02: approved follow-ups carried out

Amish approved on 2026-10-02 that every follow-up action from the open-decision sign-off be carried out. trl stays 3; nothing was built, bought or tested.

### Follow-ups (7)

| # | Follow-up | Result |
| --- | --- | --- |
| 1 | Re-run the sizing script against R8 at 9 h and R12 at 5.75 kg | Done. R8 met (8.03 h), R12 met (5.74 kg, 0.01 kg margin) |
| 2 | Weigh the prototype at TRL 4 | Not done: TRL 4 work, on hold |
| 3 | Shipping switch: model, BOM line, wiring picture, build plan | Done. Flush isolator in the bay top; BOM line 18 (USD 5); wiring picture, bay making sketch, step 15 and build plan updated. Carrier rules still to be checked before any trip (outreach, not done) |
| 4 | Name R-134a and its charge in BOM line 7 | Done. 25 g allowance (about 15 g calculated), USD 3 inside the USD 28; the technician's own price is TRL 4 work, not done |
| 5 | Approach the first candidate partner | Not done: outreach by Amish |
| 6 | Second (red) status light in the model | Done, mirrored beside the display; checks added |
| 7 | Appearance model and renders | Appearance model done (round bail, solid head top, two lights, shipping switch, labels and wordmark under line 16, no bumper); render scenes exported to /home/claude/renders/coldpod (hero, exploded, detail). Photoreal renders, card and social preview: not done, made on Amish's Mac |

The bail legs in the model are now round rods (decision 7, "round bail").

### Requirement changes (CPD-CAL-001 v0.7)

- R8: Not met to Met (9 h target). R12: Not met to Met on paper (5.74 kg against 5.75 kg).
- R15: Met to **Not met**: USD 313 against USD 310. The USD 5 shipping switch moved it from USD 308 (USD 2 under). Value-engineering target: USD 310. Estimated cost of the constructable design: USD 313 (USD 3 over the target). Deferring the switch until a trip needs it would restore USD 308. Proposed, awaiting Amish.
- Counts: 11 met, 3 at risk, 1 not met (R15), 2 not verifiable. Mass 5.74 kg.

### Documents changed

`cad/src/model.py` (69 checks pass; STEP and STL regenerated), `bom/bom.csv`, `bom/bom-notes.md`, `docs/04-calcs/sizing.py` and `01-sizing.md` (CPD-CAL-001 v0.7), `docs/03-requirements.md` (CPD-REQ-001 v0.9), `docs/02-concept.md` (CPD-PRC-001 v0.9), `docs/05-build-plan.md` (CPD-BLD-001 v0.3), `docs/06-design-decisions.md` (CPD-DEC-001 v0.4), `README.md`, drawings CPD-DWG-001 (Rev P5) and CPD-DWG-112 (Rev P2), concept media, build plan pictures (overview, wiring, step 15, step 16), `cad/src/product_model.py`.

### Cross-repo actions

None found in this repo's list.

## 2026-10-02: photoreal renders redone on the constructable design

Rendered with Blender Cycles on Amish's Mac from the updated appearance model; captioned with `.kit/photo_caption.py`; `media/card.png` and `media/social-preview.png` regenerated with `.kit/cards.py`. Views: hero, exploded, detail. image_qc passes. Appearance deviations are those logged above as proposed, awaiting Amish.

## 2026-10-03: decisions recorded

Amish decided on 2026-10-03: "Cost over target - i accept all the cost variations and overruns". Recorded for this repo: the estimated cost of USD 313 against the USD 310 target (USD 3 over), keeping the USD 5 battery shipping switch (BOM line 18).

- `docs/06-design-decisions.md`: row added to decisions made; value engineering section says the overrun was accepted by Amish on 2026-10-03.

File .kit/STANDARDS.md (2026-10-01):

---
doc_id: OHP-STD-001
title: Documentation and drawing standard
project: Open Hardware Portfolio
doc_type: Standard
version: "1.7"
status: Released
date: 2026-09-30
author: Amish Chadha
license: CC-BY-SA-4.0
revisions:
  - version: "1.0"
    date: 2026-09-24
    author: Amish Chadha
    change: First release of the standard
  - version: "1.1"
    date: 2026-09-24
    author: Amish Chadha
    change: Adopt Technology Readiness Levels (section 9) for project maturity
  - version: "1.2"
    date: 2026-09-24
    author: Amish Chadha
    change: Portfolio phase cap (section 10), concept media standard (section 11), CLAUDE.md guardrails
  - version: "1.3"
    date: 2026-09-24
    author: Amish Chadha
    change: Scale figure, interactive 3D viewer and flow diagrams added to concept media; session slash commands
  - version: "1.4"
    date: 2026-09-26
    author: Amish Chadha
    change: Every sheet and render names the project and its GitHub repository; overall dimensions, ISO centre lines and 300 dpi PNG on sheets; titles name the device and view labels state the viewing direction; optional photoreal renders with Blender
  - version: "1.5"
    date: 2026-09-27
    author: Amish Chadha
    change: Product renders (section 12), storefront images and image quality check (section 13), public release and release gate (section 14), authorship, citation and commit signing (section 15)
  - version: "1.6"
    date: 2026-09-29
    author: Amish Chadha
    change: Licensing metadata with REUSE (section 16), Zenodo DOI and Software Heritage archiving (section 17), release gate checks REUSE and a single CITATION.cff license, archive.py
  - version: "1.7"
    date: 2026-09-30
    author: Amish Chadha
    change: Concept and constructable design states; design decisions register (DEC) kept apart from the build plan; prototype build plan (BLD, section 18) with pictures by component is required TRL 3 evidence; every repo targets TRL 3 during the populate phase; build_views.py; /to-trl3 and /build-plan commands
---

# Documentation and drawing standard

Every project in the portfolio uses this standard, so that each precis, write-up and sketch looks the same and carries its own version history. The standard ships as a kit in each repo's `.kit/` folder. The kit version is in `.kit/KIT_VERSION`.

## 1. Document types and IDs

Every controlled document has a unique ID in the form `PRJ-TYP-NNN`.

- `PRJ` is the three-letter project code listed in section 7.
- `TYP` is the document type code from the table below.
- `NNN` is a sequence number within that project and type, starting at 001.

| Code | Type | Typical file |
| --- | --- | --- |
| PRC | Design precis | `docs/02-concept.md` |
| PRB | Problem statement | `docs/01-problem.md` |
| REQ | Requirements | `docs/03-requirements.md` |
| CAL | Calculation or sizing note | `docs/04-calcs/*.md` |
| DDR | Design decision record | `docs/decisions/*.md` |
| BOM | Bill of materials | `bom/bom.csv` |
| DWG | Drawing or sketch sheet | `cad/drawings/*.svg` |
| BLD | Prototype build plan (section 18) | `docs/05-build-plan.md` |
| DEC | Design decisions register (section 18) | `docs/06-design-decisions.md` |
| TST | Test plan or test report (front matter adds `environment: lab` or `relevant`) | `docs/05-tests/*.md` |

Example: `TBK-PRC-001` is the ThermaBrick design precis.

## 2. Revision scheme

| Artifact | While in draft | When released | Change after release |
| --- | --- | --- | --- |
| Documents | 0.1, 0.2, 0.3 ... | 1.0 | 1.1 for minor edits, 2.0 for a design change |
| Drawings | Rev P1, P2 ... (preliminary) | Rev A | Rev B, C ... |

- Every change to a controlled document adds a row to its revision history before the commit.
- The `version` field in front matter always equals the newest row in `revisions`. The renderer rejects a document where they differ.
- Status is one of `Draft`, `In review`, `Released` or `Superseded`. Draft and In review documents print with a status band on every page.
- Every release is tagged in Git as `<doc_id>/v<version>`, for example `TBK-PRC-001/v1.0`. Drawings are tagged `TBK-DWG-001/revA`.
- Git history is the full audit trail. The in-document revision table is the human-readable summary.

## 3. Document front matter

Every Markdown document under version control starts with this block:

```yaml
---
doc_id: TBK-PRC-001
title: ThermaBrick design precis
project: ThermaBrick
doc_type: Precis
version: "0.1"
status: Draft
date: 2026-09-24
author: Amish Chadha
license: CERN-OHL-S-2.0
revisions:
  - version: "0.1"
    date: 2026-09-24
    author: Amish Chadha
    change: Initial draft
---
```

Quote version numbers so YAML keeps `1.0` as text instead of turning it into a number. List revisions newest last.

## 4. Writing style

- Chicago Manual of Style.
- No em dashes. Restructure the sentence instead.
- Lead each section with its conclusion, then support it.
- SI units throughout, in the form `12 kW`, `450 °C`, `3.2 m`. Imperial values may follow in parentheses.
- Number every figure and table ("Figure 2", "Table 1") and give each a caption.
- State every assumption in the calculation that depends on it.
- Put safety notes in a blockquote starting with **Safety:**.

## 5. Visual identity

| Element | Specification |
| --- | --- |
| Typeface | IBM Plex Sans for text, IBM Plex Mono for code and values (SIL Open Font License, bundled in `.kit/fonts`) |
| Ink | `#111827` |
| Secondary text | `#4B5563` |
| Rules and grid | `#D1D5DB` |
| Accent (one only) | `#0F766E` teal |
| Document page | US Letter, 20 mm margins |
| Drawing sheet | ANSI B landscape (431.8 x 279.4 mm) |
| Footer | Document ID, version, status, license and designmolecule.com on every page |

## 6. Drawing and sketch conventions

- Units are millimeters unless the title block says otherwise.
- Third-angle projection, marked with the symbol in the title block.
- Line weights: visible outlines 0.5 mm, hidden lines 0.25 mm dashed, center lines 0.18 mm chain.
- The title block contains the project, title, drawing number, revision, scale, units, projection, sheet, author, date, material or notes, and license.
- Every sheet and every render names the project and its GitHub repository (from `repo:` in `project.yaml`), at the top of the sheet and in the title block, so a printed or forwarded sheet is never anonymous.
- The drawing title names the device, not only the drawing type (for example "Handheld near-infrared resin scanner: general arrangement").
- Every view label states its scale and viewing direction (for example "Scale 1:1; side elevation looking along +Y"), and every isometric or render states where it is seen from.
- Orthographic views generated with `add_ortho` carry overall dimensions (length and depth on the top view, height on the front view) and ISO 128 centre lines on cylinders; hidden lines are dashed. Tolerances are not shown before TRL 4.
- Sheets are exported as SVG, PDF and a 300 dpi PNG.
- The revision table in the top right of the sheet lists every revision.
- Concept sketches use the same sheet and title block and carry the label "CONCEPT, NOT FOR FABRICATION".
- Geometry comes from `cad/src/*.py` (build123d). Sheets are generated by `.kit/drawing.py` and never edited by hand.

## 7. Project codes

| Code | Project | Code | Project | Code | Project |
| --- | --- | --- | --- | --- | --- |
| TBK | ThermaBrick | PCF | PicoFlow | HLT | HelioLite |
| CCB | CharCube | DRN | DustRunner | TRT | TremorTrace |
| STC | StepCue | FXH | FlexHand | CPD | ColdPod |
| SCL | SunClave | STR | SteamRoot | GGD | GrainGuard |
| SDL | SeedLine | ZBX | ZeerBox | RMS | RootMesh |
| DWD | DewDrive | SSK | StillStack | PPR | PotPress |
| WWT | WaterWatch | LMF | LumaFlow | FCL | FieldCell |
| CNP | ConePro | CVC | CulvertCrawl | EGD | EmberGuard |
| SNF | SnapFrame | CGM | CargoMule | SCM | StepClimber |
| SWC | SwapCell | PLP | PalletPilot | FTK | FlatTrike |
| WWK | WaterWalker | GRR | GrowRider | SSP | SunSpoke |
| SGN | StepGen | PBX | PowerBox | WML | WasteWise-ml |
| WSC | WasteWise Scan | RFE | ReflowEconomy | | |
| OHP | Portfolio-wide | | | | |

## 8. Build and publish

- `python .kit/render.py` checks every controlled document and renders it to `docs/pdf/<doc_id>_v<version>.pdf`.
- `python .kit/drawing.py` (called from each project's `cad/src/sheets.py`) builds drawing sheets as SVG and PDF in `cad/drawings/`.
- The GitHub Action in `.github/workflows/docs.yml` runs the checks on every push and attaches PDFs to a GitHub Release whenever a release tag is pushed.
- Public releases follow section 14: `python .kit/release_gate.py` must pass, and the release tag is `v0.<TRL>.0` (for example `v0.3.0` at TRL 3).

## 9. Technology Readiness Level (TRL)

Each project states its maturity as a Technology Readiness Level on the NASA and US DOE 1 to 9 scale. The TRL rates this specific design, not the underlying technology. A sand battery is commercial elsewhere, but a new sand battery design starts at TRL 2 until evidence shows otherwise.

| TRL | Definition | Evidence the repo must contain |
| --- | --- | --- |
| 1 | Basic principles observed | Problem statement (PRB) |
| 2 | Technology concept formulated | Draft precis (PRC) and requirements (REQ) |
| 3 | Analytical or experimental proof of concept | Calculation note (CAL), working build123d model with STEP export, drawing sheet (DWG), priced BOM with every unit cost filled in, prototype build plan (BLD) with pictures, `design_state: constructable` |
| 4 | Components validated in the lab | Test report (TST) with `environment: lab`, build log entries |
| 5 | Validated in a relevant environment | Test report (TST) with `environment: relevant` |
| 6 | System prototype demonstrated in a relevant environment | Precis at version 1.0 or later with status Released, a drawing at a lettered revision (Rev A or later), and a system-level TST with `environment: relevant` |
| 7 to 9 | Operational demonstration through proven in service | Beyond portfolio scope; claim only with a named deployment partner and evidence |

Rules:

- `project.yaml` records `trl` (current level), `trl_target` (the level the current effort aims for) and `trl_evidence` (the files that support the claim).
- `python .kit/render.py --check` fails if the evidence for the claimed TRL is missing. CI runs this check on every push.
- Documentation alone cannot go past TRL 3. TRL 4 and above require hardware and a test report.
- TRL and visibility are independent. A repo can be public at TRL 3 as a documented design ready to build.
- A change of TRL is recorded in the build log with the date and the evidence that justified it.

## 10. Portfolio phase and TRL cap

`.kit/PHASE.yaml` sets the current phase. During the **populate** phase every repo is capped at **TRL 3**: `trl` and `trl_target` may not exceed 3, and the check fails if they do. Every repo targets the cap: `trl_target` must equal 3, so a new repo is taken all the way to TRL 3 (scaffold, populate and advance, see `/to-trl3`). Work that belongs to TRL 4 or later (building or testing hardware, test articles, test plans and reports, build-log entries, purchasing lists, PCB layouts) must not be started. The prototype build plan (BLD, section 18) is TRL 3 paper work and is required. Where it already exists it is kept, flagged in the check output, and not extended. Only Amish changes `PHASE.yaml`.

Every repo carries a `CLAUDE.md` with the working rules for AI sessions: the TRL cap, decision rights (nothing is recorded as decided unless Amish decided it), one step per session, and a mandatory `docs/REVIEW.md` before stopping.

## 11. Concept media

Every repo at TRL 2 or above explains its idea visually. Media are generated from a build123d massing model with `.kit/concept.py`, never drawn by hand, so they stay in step with the design.

| File | Required | Purpose |
| --- | --- | --- |
| `media/hero.png` | TRL 2+ | Shaded isometric render with a 1.75 m person for scale; the website card image |
| `media/concept-blueprint.png` and `.pdf` | TRL 2+ | Blueprint concept sheet: orthographic and isometric views, scale, key figures, title block |
| `media/model.glb` and `media/viewer.html` | TRL 2+ | Interactive 3D viewer (glTF plus model-viewer) for the website |
| `media/cutaway.png` | When the inside matters | Section view showing internal parts |
| `media/exploded.png` | Recommended | Exploded view with numbered callouts matching the BOM |
| `media/flow.png` | When energy or material moves | System, energy or material flow diagram with losses |

Session commands in `.claude/commands/` (`/populate`, `/advance-trl3`, `/rein-in`, `/refresh-media`) carry the standard prompts, so every Claude Code session starts from the same instructions.

At TRL 2 a massing model is enough: correct overall proportions and main components. All concept media carry "CONCEPT, NOT FOR FABRICATION". The check warns when required media are missing at TRL 2 and fails at TRL 3.

## 12. Product renders

Every repo at TRL 3 shows the product as it would look, not only as a massing model.

- `cad/src/product_model.py` is the appearance model. It defines `product_parts()` (named parts with a shape and a material), `TITLE` ("Name: what it is") and `RENDER_VIEWS`. It is for renders only: every main dimension comes from `cad/src/model.py`, never typed in again.
- Where the appearance model departs from `model.py` (a chamfer, a label, a fastener drawn for realism), record the deviation in `docs/REVIEW.md` as "Proposed, awaiting Amish".
- Scale comes from context, not from a floating figure: a hand or forearm for handheld objects, and the posed mannequin (`mannequin()` in `.kit/context_parts.py`: stand, walk, push, ride, sit, reach) for anything a person uses at body scale.
- Renders are made with `.kit/export_views.py` (one scene per view) and `.kit/photoreal.py` (Blender Cycles), then captioned with `.kit/photo_caption.py`. Files are `media/render-<view>.png`; `media/render-hero.png` is required.
- Every caption names the project, the repository and the viewing direction, and carries "CONCEPT, NOT FOR FABRICATION".
- Captions never sit on the render. `.kit/photo_caption.py` adds a header band (title, concept label, repository) above the render and a footer band (view note) below it, wraps every line to the image width, and steps the font down to a floor before adding a line.
- The README opens with `media/render-hero.png`.
- Software-only and scene repositories (no single product) may use a scene render as the hero instead of a product model.

## 13. Storefront images

Two images, both made from `media/render-hero.png` by `python .kit/cards.py .`:

| File | Size | Purpose |
| --- | --- | --- |
| `media/card.png` | 800 x 800 | Square thumbnail for the organization profile page |
| `media/social-preview.png` | 1280 x 640, under 1 MB | GitHub social preview, shown when a repository link is shared |

- The social preview shows the area, name, one-line description, the first sentence of the pitch, the brand line and the repository address. Design Molecule repos read "Design Molecule · open hardware concept, TRL n"; OpenRatio repos read "OpenRatio · research and educational prototype, TRL n".
- GitHub has no API for the social preview. Upload it under the repository's Settings, Social preview, on release day.
- Regenerate both images whenever `render-hero.png` changes.

### Image quality

Every render, card and social preview must be clear and readable. `python .kit/image_qc.py` checks each one, and the release gate blocks on any failure:

| Check | Rule |
| --- | --- |
| Layout | Made by the current `photo_caption.py` or `cards.py`, which store the text layout in the PNG |
| Text inside the image | Every line at least 1.2 % of the image width from each edge; nothing runs off the side |
| No overlap | No line of text touches another line, and no caption text sits on the render |
| Text size | Render captions at least 1.05 % of the image width in pixel height (17 px at 1600 px); social preview text at least 16 px |
| Resolution | Renders at least 1200 px wide; card 800 x 800; social preview 1280 x 640 and under 1 MB |
| Sharpness | The render is not blurred or upscaled (edge sharpness at least 15 on the `image_qc.py` scale) |

Long titles and notes wrap to more lines rather than shrinking below the floor. The social preview shortens the pitch sentence with an ellipsis only if it cannot fit at the smallest size.
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

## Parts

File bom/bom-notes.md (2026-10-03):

# BOM notes

- Item numbers match the exploded view (`media/exploded.png`), Table 1 of the design precis (CPD-PRC-001) and drawing CPD-DWG-001. Items 16 and 17 are fixings and construction parts, and item 18 is the battery shipping switch; item 17's printed parts are in the model, the rest of 16 and 17 is not.
- Every line is priced. Prices are indicative estimates in USD for single-unit prototype quantities, by supplier type; none is a supplier quote.
- Total: $313 against the `budget_usd: 310` value-engineering target (a hypothetical control target, CPD-DDR-002 N3): $3 over the target. The VIPs (item 4) and the thermosiphon (item 7) remain the largest price uncertainties. The total is checked by `docs/04-calcs/sizing.py` (CPD-CAL-001, L2).
- Changes at TRL 3: item 7 now covers the evaporator can and a charged loop thermosiphon sized in CPD-CAL-001 ($12 to $28); item 8 is the lower-current TEC1-12703 class ($6 to $5); item 12 names a filtered buck driver; item 6 uses a printed rack.
- Changes from the recommendations Amish accepted on 2026-09-25 (CPD-DDR-002): item 2 adds the 1.5 mm aluminium lid cold plate ($8 to $12, with $1 less filament for the 5 mm cap); item 14 adds the 3 °C liner cut-out ($10 to $13); item 12 uses a buck-boost Peltier driver ($22 to $26); items 1 and 10 use thinner printed walls ($18 to $17 and $8 to $6). Total $295 to $303.
- Item 7: the loop is charged with R-134a (decided 2026-10-02, CPD-DEC-001); the charge is set by the refrigeration technician from the loop volume. Item 16 carries the labels and wordmark.
- The payload (insulin pens or vaccines) is not supplied and not costed.
- The SwapCell pack is not used by ColdPod, so no shared SwapCell cost applies.
- Changes to make the design buildable (CPD-DDR-003, accepted by Amish on 2026-10-02): item 1 adds printed pads, towers and rim slots; item 2 folds the lid cold plate into a tray bonded to the lid plug ($12 to $13); item 4 lists the seven panels to order; item 5 lists the pouch shapes; item 6 stands the liner on printed feet and a collar; item 7 specifies the can's rim flange and slots, the bent risers and the drilled cold block; item 14 moves the payload probe above the pens; item 16 lists the fixings; new item 17 covers the printed construction parts, inserts, foam strip and drain tube ($4). Total $303 to $308.
- Carried out on 2026-10-02 from the approved decisions: new item 18, the battery shipping switch ($5, catalog-class estimate; in the model, in the bay top); item 7 names R-134a with a 25 g charge allowance and a $3 allowance inside its $28 for the gas and a share of the technician's time, to be replaced by the technician's own price at TRL 4; item 15 lists the second (red) status light now in the model. Total $308 to $313.

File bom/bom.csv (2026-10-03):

item | qty | spec | supplier | unit_cost_usd | make_buy | notes
1 Outer shell | 1 | 3D-printed PETG or ASA tub, 3 mm walls, 261 x 196 x 164.5 mm; three slots open at the rim on the +X end (two pipe slots 10 mm wide, one cable slot 6 mm wide); printed pads with M3 heat-set inserts for the end housings (8) and latches (2), M5 pads for the handle pivots (2), and two towers for the cold block frame | Self (PETG or ASA filament from a filament supplier) | 17.00 | make | Material cost only; about 0.70 kg printed (CPD-CAL-001, K1); walls 4 to 3 mm by CPD-DDR-002; pads, towers and rim slots added by CPD-DDR-003 because no fixing may pass through a wall with a VIP behind it; needs a printer bed of 300 mm or more; estimate
2 Lid with cold plate, gasket and latches | 1 | Printed cap 261 x 196 x 5 mm, EPDM closed-cell foam gasket strip 10 x 3 mm, two draw latches with keepers on the front, lid switch; lid cold plate tray folded from 1.5 mm aluminium, 204 x 139 mm, 16.5 mm deep, with a 6 mm inward top lip bonded to the lid VIP plug with acrylic foam tape; it lands on the evaporator can's rim flange; lid VIP plug in item 4, lid PCM pack in item 5 | Self; plate from a local sheet metal shop; gasket and latches from a hardware distributor | 13.00 | make | Cap material and small parts $7 (cap 8 to 5 mm), tray about $6 (flat plate $5 by CPD-DDR-002, folded into a tray by CPD-DDR-003); estimate
3 Bail handle and shoulder strap | 1 | Folding bail handle rated 10 kg or more, padded 38 mm strap | Hardware or outdoor store | 10.00 | buy | Catalog-class price; estimate
4 Vacuum-insulated panel set | 1 | Seven panels 25 mm, fumed silica core, metallized film, made to size: floor 255 x 190; front and back 255 x 136.5 tall; battery end 140 x 136.5; cooling end lower 140 x 68 and upper 140 x 40.5 (around a 28 mm foam strip); lid plug 204 x 139. Tolerance plus 0, minus 1 mm | VIP manufacturer (custom small order) | 60.00 | buy | Largest cost uncertainty; small custom orders may cost more; foam variant documented as a low-cost option (CPD-DDR-001 D7); panel list from CPD-DDR-003
5 PCM packs | 1 | About 0.94 kg organic PCM melting at 5 °C (Rubitherm RT 5 HC class) in sealed HDPE pouches: jacket pouches in the evaporator can (0.67 kg: a floor pouch with corner reliefs for the liner feet, two long side pouches, two end pouches at the battery end and three narrow pouches between and beside the risers at the cooling end) and a lid pack in the lid tray (0.27 kg) | PCM supplier (Rubitherm distributor or equivalent) | 25.00 | buy | Masses from the model (CPD-CAL-001, C2); estimate
6 Aluminium liner and payload rack | 1 | 1.5 mm aluminium can 175 x 110 x 80 mm outside, folded and welded, with a 7 mm grommeted cable hole; stands on four printed feet and is centred by a printed collar (item 17); printed PETG rack holding 24 pens in 4 layers of 6 | Local sheet metal shop; rack self-printed | 12.00 | make | Estimate
7 Evaporator can and loop thermosiphon | 1 | 1.0 mm aluminium can around the PCM jacket (four sides and floor, 205 x 140 x 95 mm) with a 5 mm inward rim flange, two riser slots open at the rim and a 6 mm cable hole; 8 mm copper evaporator ring (25 mm corner bends) bonded into the can's bottom inside corner with thermally conductive epoxy, two risers with 17.5 mm bends brazed in with tees; aluminium cold block 60 x 44 x 10 mm with two 8.1 mm tube sockets, a 6 mm condensing passage and two tapped M3 holes, tubes joined with aluminium-to-copper brazing rod; 6 mm charge stub; R-134a working fluid (non-flammable, class A1), charge allowance 25 g (about 15 g calculated from the loop volume, CPD-CAL-001 K1), set by the technician | Sheet metal shop for the can; refrigeration or HVAC supplier for tube and charging | 28.00 | make | Sized in CPD-CAL-001 (sections G and H); brazing, leak testing and charging need a refrigeration technician; R-134a named by CPD-DEC-001 (2026-10-02); the $28 holds an allowance of $3 for the gas and a share of the technician's charging time, to be replaced by the technician's own price at TRL 4; estimate
8 Peltier module | 1 | 40 x 40 mm, 127 couples, Imax about 3 A (TEC1-12703 class) | Electronics distributor | 5.00 | buy | Chosen over the 12706 in CPD-CAL-001 section E; estimate
9 Hot-side heat sink and fan | 1 | Finned aluminium sink about 80 x 80 x 30 mm, 70 mm 12 V fan, finger guard; 0.50 K/W or better sink to air with the fan | Electronics distributor | 12.00 | buy | Estimate
10 End housings | 1 | Printed cooling head (+X, 60 mm) and battery and electronics bay (-X, 45 mm), 2 mm walls, vented, drain for condensate | Self (PETG or ASA filament) | 6.00 | make | Material cost only; about 0.29 kg printed; walls 3 to 2 mm by CPD-DDR-002; estimate
11 LiFePO4 pack | 1 | 4S1P 32700 cells, 12.8 V 6 Ah (76.8 Wh), 4S BMS with charge temperature cut-off, fuse, holder | Battery distributor | 35.00 | buy | Estimate
12 Power board | 1 | USB-C PD sink (20 V, 45 W or more), 12 V input (10 to 15 V) with reverse-polarity protection, LiFePO4 charger, buck-boost Peltier driver with LC filter (smooth DC), fan driver; cold-block and liner cut-outs wired in series in the Peltier supply; modules on perfboard | Electronics distributor | 26.00 | buy | Off-the-shelf modules; no custom PCB; buck-boost in place of buck adds about $4 (CPD-DDR-002); estimate
13 Logger controller | 1 | nRF52840 module with real-time clock and 2 MB flash | Electronics distributor | 15.00 | buy | Estimate
14 Temperature sensors and liner cut-out | 1 | Payload probe: glycol-buffered vial 10 mm x 40 mm with a digital sensor, lying above the top layer of pens; liner probe, cold-block probe, ambient sensor, accuracy ±0.5 °C or better; bimetal cut-out thermostat on the liner opening at 3 °C, in series with the cold-block cut-out | Electronics distributor | 13.00 | buy | Liner cut-out about $3 (CPD-DDR-002); probe moved above the pens by CPD-DDR-003; estimate
15 E-paper display and alarm | 1 | 2.13 in e-paper, buzzer, two status lights (one green and one red, mirrored either side of the display) | Electronics distributor | 15.00 | buy | Estimate
16 Wiring and hardware | 1 | Wire, 8-core sensor cable, connectors, fuses, fasteners (M3 and M5 screws, M3 standoffs), grommets, sealant, closed-cell foam tape for the cold block and pipes, labels | Hardware store | 12.00 | buy | Not modelled; estimate
17 Construction parts | 1 | Printed PETG: liner feet (4) and collar, block frame with drip tray, three slot fillers, cable duct cover, cell cradle; 22 M3 and 2 M5 brass heat-set inserts; 4 mm drain tube; polyurethane foam strip 28 mm for the pipe crossing; acrylic foam tape | Self (filament); hardware distributor | 4.00 | make | Added by CPD-DDR-003 to make the design buildable; about 0.09 kg printed; estimate
18 Battery shipping switch | 1 | Panel-mount rotary battery isolator, 10 mm hole, rated 30 V DC and 10 A or more, lockable off position, flush in the battery bay top; in series with the pack positive lead ahead of the fuse | Electronics or marine distributor | 5.00 | buy | Catalog-class price for a small isolator; added by CPD-DEC-001 (2026-10-02, battery removal) so the pack can be isolated before any field or air travel; estimate

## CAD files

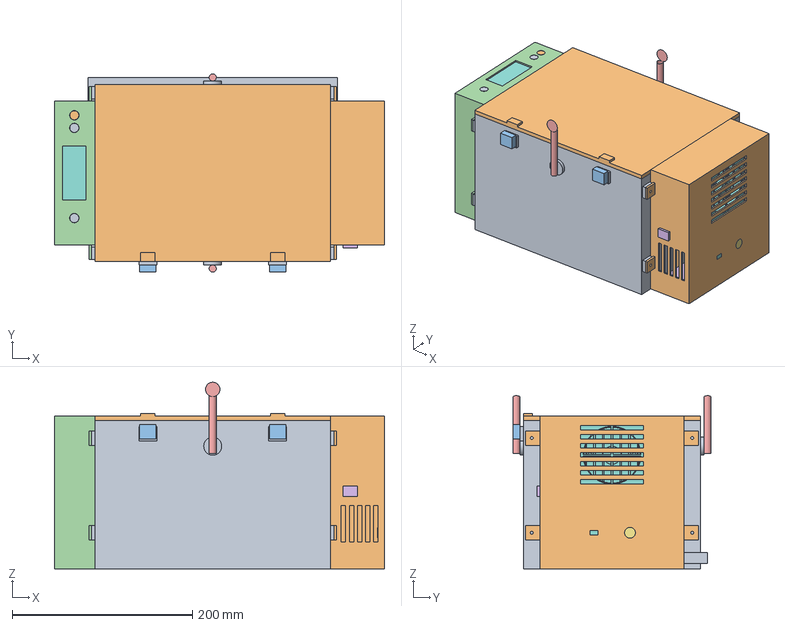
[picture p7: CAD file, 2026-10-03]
cad/step/coldpod-assembly.step
366.0 x 220.0 x 207.0 mm

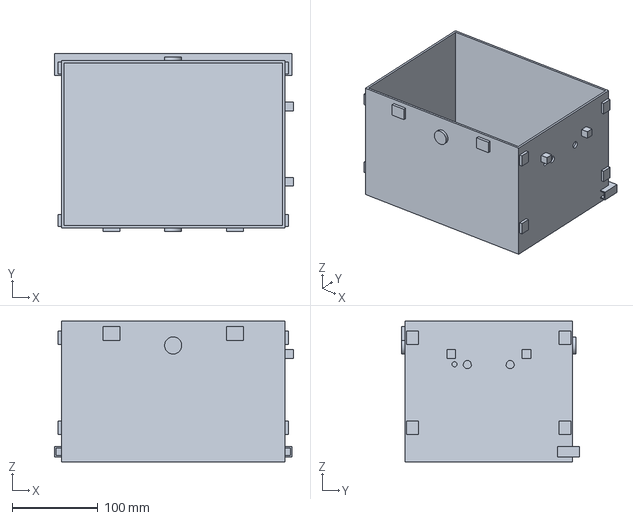
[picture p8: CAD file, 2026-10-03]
cad/step/shell.step
279.0 x 208.0 x 164.5 mm

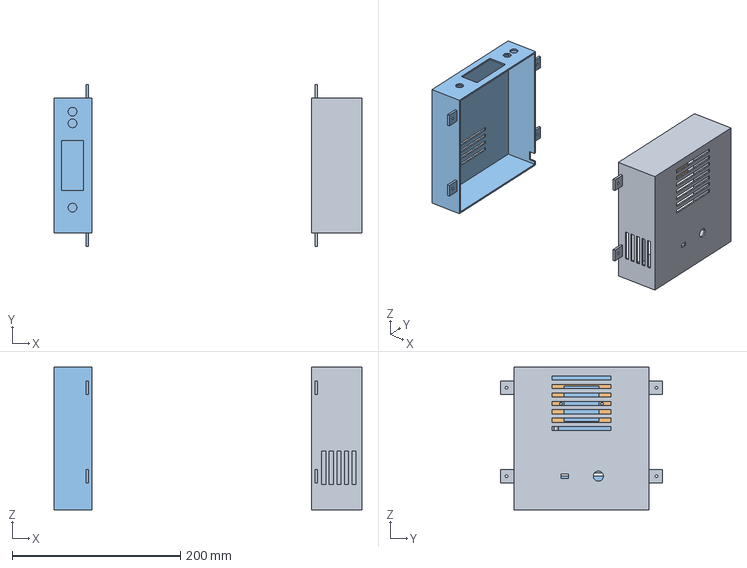
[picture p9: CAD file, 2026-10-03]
cad/step/end-housings.step
366.0 x 192.0 x 169.5 mm

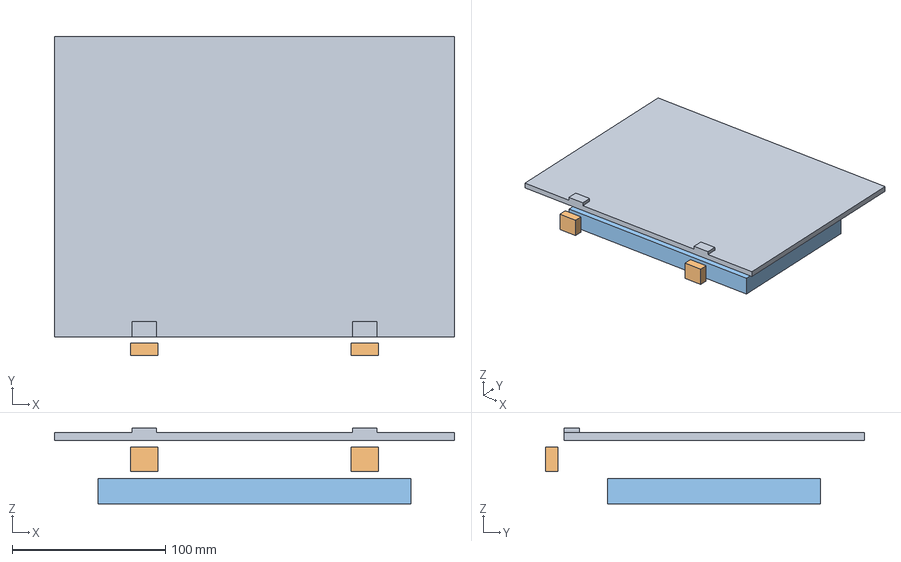
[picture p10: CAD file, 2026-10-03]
cad/step/lid.step
261.0 x 208.0 x 49.5 mm

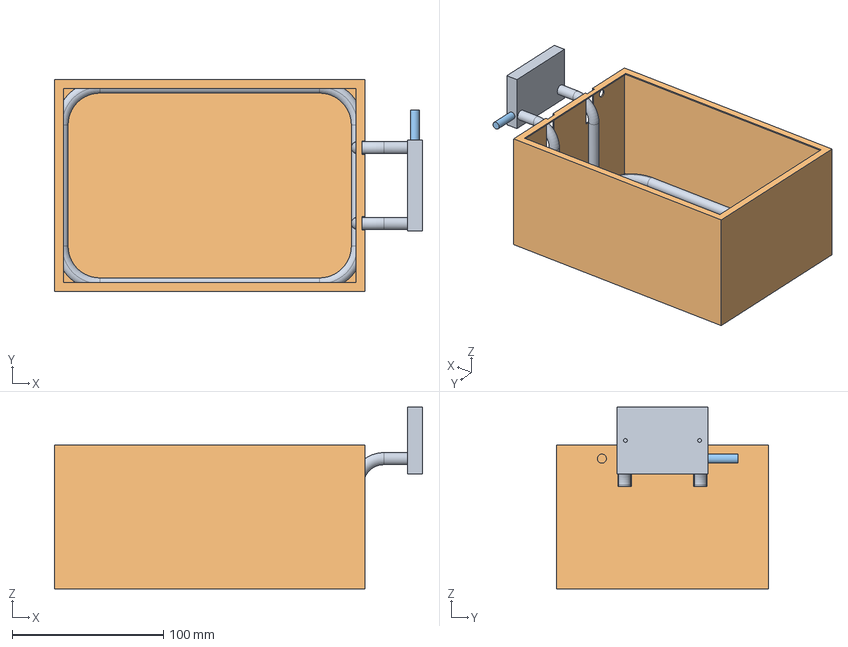
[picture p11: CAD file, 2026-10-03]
cad/step/evaporator-thermosiphon.step
243.0 x 140.0 x 120.0 mm

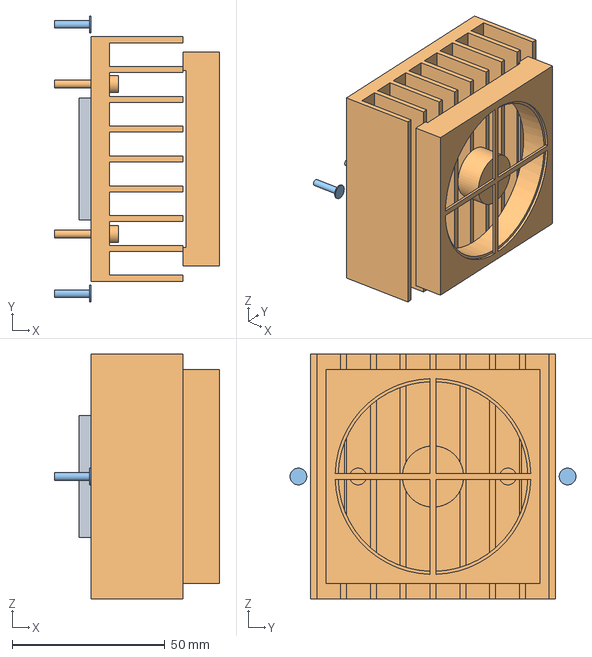
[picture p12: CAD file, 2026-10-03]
cad/step/cooling-head.step
54.0 x 93.5 x 80.0 mm

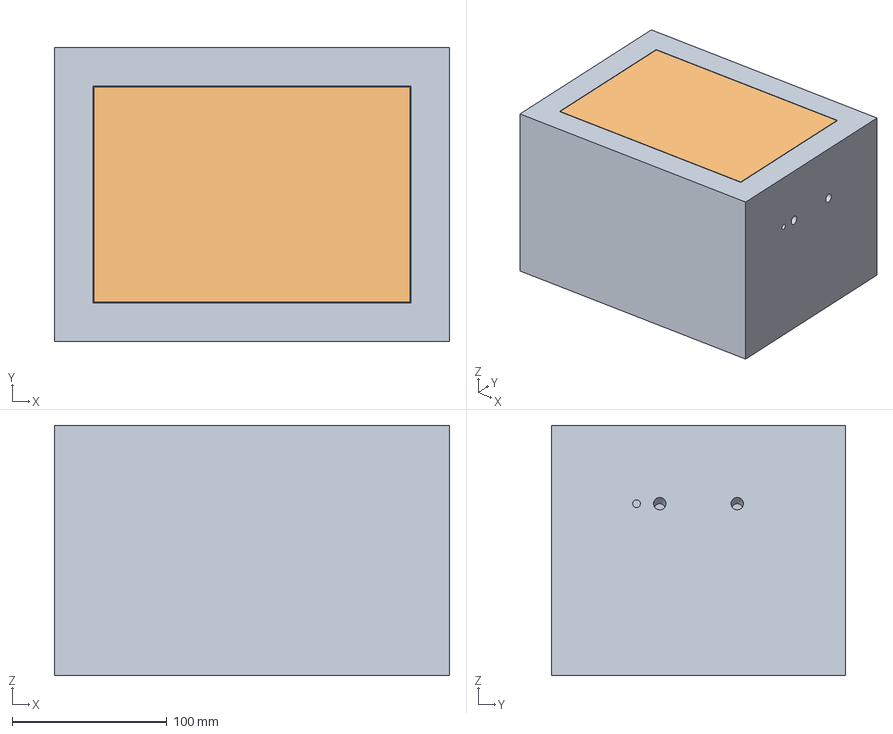
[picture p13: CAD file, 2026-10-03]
cad/step/vip-set.step
255.0 x 190.0 x 161.5 mm

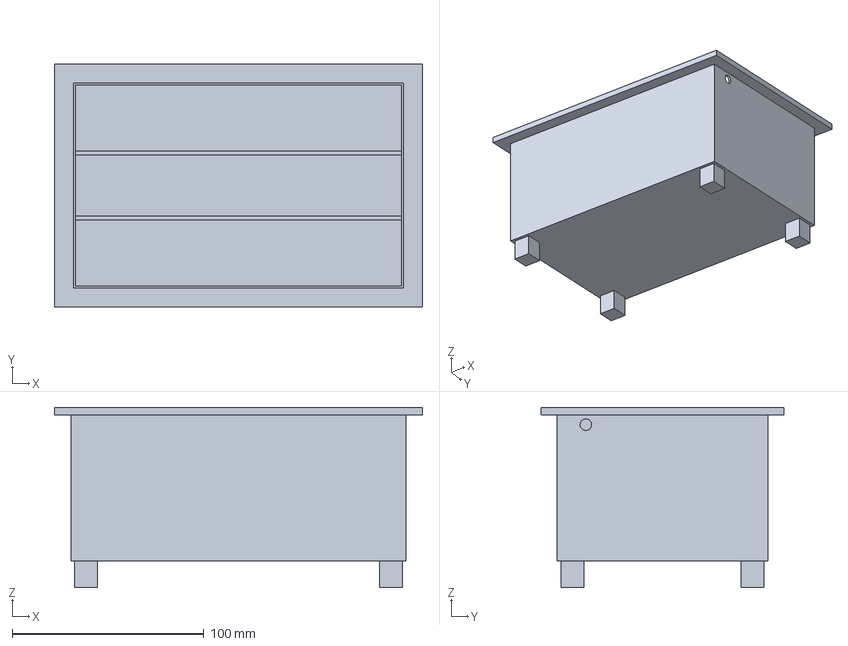
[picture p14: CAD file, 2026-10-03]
cad/step/liner-rack.step
192.0 x 127.0 x 94.0 mm

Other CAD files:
cad/stl/coldpod-assembly.stl
cad/stl/cooling-head.stl
cad/stl/end-housings.stl
cad/stl/evaporator-thermosiphon.stl
cad/stl/lid.stl
cad/stl/liner-rack.stl
cad/stl/shell.stl
cad/stl/vip-set.stl

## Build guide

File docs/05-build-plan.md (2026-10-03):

---
doc_id: CPD-BLD-001
title: ColdPod prototype build plan
project: ColdPod
doc_type: Build plan
version: "0.3"
status: Draft
date: '2026-10-02'
author: Amish Chadha
license: CERN-OHL-S-2.0
revisions:
  - version: "0.1"
    date: '2026-10-01'
    author: Amish Chadha
    change: First build plan; design made constructable (CPD-DDR-003, Draft, open for Amish's review)
  - version: "0.2"
    date: '2026-10-02'
    author: Amish Chadha
    change: "CPD-DDR-003 accepted (2026-10-02); loop working fluid R-134a in section 3 and safety stop S2"
  - version: "0.3"
    date: '2026-10-02'
    author: Amish Chadha
    change: "Second status light and battery shipping switch added to the battery bay, wiring and steps; pictures redrawn"
---

# ColdPod prototype build plan

**Plan, not yet built.** How to build the first proof-of-concept prototype, component by component. Building and testing to it is TRL 4 work. Decisions still to be made are kept in the design decisions register ([docs/06-design-decisions.md](06-design-decisions.md)), not here.

ColdPod is a research and educational prototype, not a medical device. Never use a prototype built to this plan to carry real vaccines or insulin.

## 1. What you are building

Figure 1. Every component, pulled apart and numbered in build order

*Figure 1. Every component pulled apart and numbered in build order. The cooling head is at the right-hand end, the battery bay at the left.*

The prototype is one ColdPod carry case, 366 x 220 x 207 mm with the handle up. From the inside out it is a printed rack of 24 insulin pens in an aluminium liner; a jacket of sealed pouches of phase-change material (a paraffin that melts at 5 °C) inside an aluminium evaporator can; seven vacuum-insulated panels (VIPs); and a 3D-printed shell. A copper loop bonded to the bottom of the can carries heat out to an aluminium cold block, a Peltier module and a finned heat sink with a fan in a printed cooling head at the right-hand end; the battery, logger and display sit in a printed bay at the left-hand end. Figure 1 shows the 23 component groups in the order you make or fit them. Fifteen are made: the shell, the evaporator can, the copper loop, the cold block, three slot fillers, the liner, its feet and collar, the rack, the block frame, the two end housings, the cell cradle, the cable duct cover, the lid cold plate tray and the lid cap. Everything else is bought: the VIPs (to size), the PCM pouches, the Peltier module, heat sink and fan, the battery cells, the electronic modules, the handle and the latches. The work is 3D printing, simple sheet-metal work done by a local shop, tube bending, brazing and charging the loop (by a refrigeration technician), and wiring bought modules. The parts cost about $313, from the bill of materials.

> **Safety:** The prototype holds a 76.8 Wh lithium iron phosphate battery, about 0.94 kg of combustible paraffin in sealed pouches, a sealed refrigerant loop under pressure and a heat sink that reaches about 53 °C. Keep the battery fuse out until section 6 says otherwise. Brazing and charging the loop are done by a refrigeration technician before any plastic, VIP or PCM is near it. A punctured VIP loses its insulation without any visible sign: never cut, drill or press a sharp tool against one.

## 2. What changed to make it buildable

The concept showed what ColdPod does; many of its parts had no fixing or could not be put together as drawn. Each change below keeps what ColdPod does. All of them are recorded in decision record CPD-DDR-003, which Amish accepted on 2026-10-02. One rule drives most of them: there is a VIP behind every wall of the shell, so no screw, rivet or drill may pass through a shell wall, and every outside fixing lands on a printed pad or tower with a threaded insert.

*Table 1. Changes from the concept.*

| Component | The concept had | The buildable design has | Why |
| --- | --- | --- | --- |
| Payload probe | A probe standing in a corner of the liner, overlapping the pens | A 10 x 40 mm vial lying across the top layer of pens at the cooling end (Figure 15) | Keeps all 24 pens |
| Copper loop | A ring floating in the PCM, touching nothing | The ring bonded into the bottom inside corner of the can (Figure 6) | The can becomes the evaporator it was meant to be |
| Risers and pass-throughs | A right-angle turn inside a 14 mm gap; round holes in the can and shell | Bends of 17.5 mm radius inside a taller foam strip; slots open at the rim, closed by printed fillers (Figure 8) | A one-piece sealed loop can be bent, charged and lowered in |
| Cold block | No passage and no joint to the tubes | Tube sockets, a drilled passage and a charge stub, joined by aluminium-to-copper brazing (Figure 9) | Makes a sealed condenser |
| Peltier stack | Hung on the copper tubes | A printed frame holds the block to two towers on the shell; two screws clamp the module (Figure 10) | The shell, not the tubes, carries the stack |
| End housings, handle, latches | No fixings | Printed pads with threaded inserts on the shell; ears on the housings (Figures 3 and 19) | No screw may pass through a VIP wall |
| Liner and lid plate | Liner resting on a pouch; a flat lid plate on a 1 mm can edge, not fixed to the lid | Liner on printed feet and a collar; a 5 mm rim flange on the can; a folded lid tray bonded to the lid plug (Figures 14 and 26) | Location, a real landing for the lid tray, and a lid that lifts off as one |
| VIPs | One solid box | Seven panels bought to size (Figure 4) | VIPs cannot be cut |
| Electronics | Floating in the housings | Standoffs, a cell cradle, a display window | Fixings for bought modules |
| Condensation | Would drip on the power board | A drip tray and drain tube (Figure 17) | The cooling head drains outward |
| Cables | No route out of the cavity or between the two ends | Grommets at the cooling end and a duct cover along the back (Figure 24) | Every lead has a path |

The case is 8 mm wider (the handle pivots stand on pads) and weighs about 5.74 kg empty, against 5.53 kg for the concept.

## 3. Making the components

Make and check each component before the assembly step that needs it. Sizes are in millimetres. "Front" is the face with the latches; "left" and "right" are as seen from the front, so the cooling head is on the right. Workshop tolerance is 0.5 mm unless a step says otherwise; drawings do not carry tolerances before TRL 4.

### 3.1 Outer shell

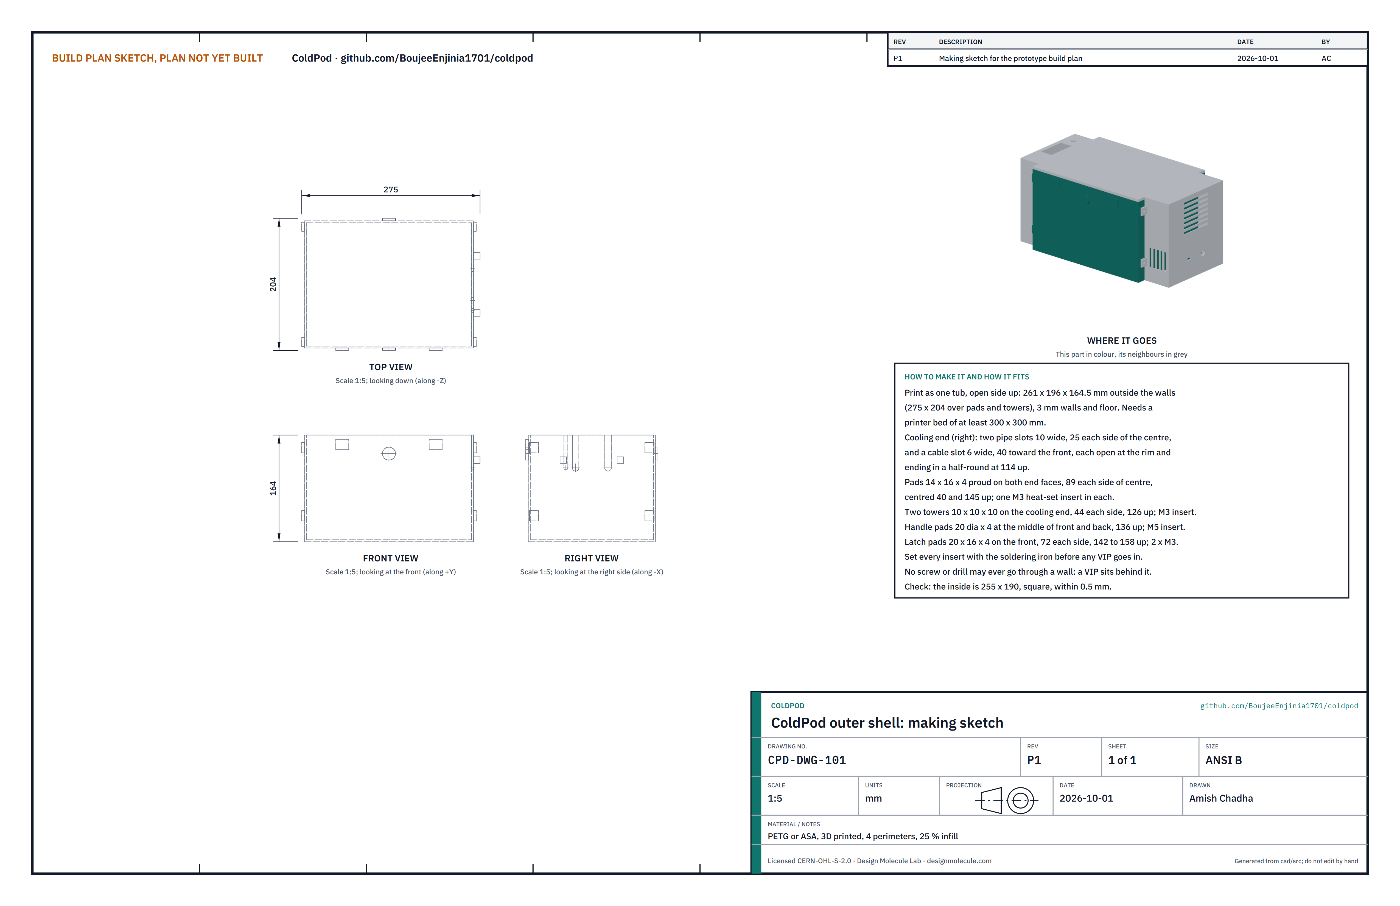
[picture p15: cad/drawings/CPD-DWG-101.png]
Figure 2. Making sketch of the outer shell


*Figure 2. Outer shell making sketch (CPD-DWG-101).*

**What it is and what it is made from.** The open-topped tub that protects the VIPs and carries every outside fixing. PETG or ASA, 3D printed with four perimeters and 25 % infill, 261 x 196 x 164.5 mm outside the walls, 3 mm walls and floor.

**How to make it.**

1. Print the tub open side up on a printer with a bed of at least 300 x 300 mm and 180 mm of height. Let it cool on the bed.
2. Check that the right-hand end has two pipe slots 10 wide, 25 each side of the centre, and a cable slot 6 wide, 40 toward the front. Each is open at the rim and ends in a half-round 114 up from the bottom.
3. Check the printed pads: four on each end face (14 wide, 16 tall, 4 proud, 89 each side of centre, 40 and 145 up); two towers 10 x 10 x 10 on the right-hand end (44 each side of centre, 126 up); a round pad 20 across at the middle of the front and back (136 up) for the handle; two pads on the front (72 each side of centre, 142 to 158 up) for the latches.
4. Set the threaded inserts with a soldering iron and an insert tip: one M3 insert in each end pad and tower, one M5 insert in each handle pad, two M3 inserts in each latch pad. Do this now, before any VIP is near the shell.
5. Clean out any stringing inside; the inside faces must be smooth and flat for the VIPs.

**How it fits the parts next to it.** The VIPs fill it exactly (section 3.2). The cooling head and battery bay screw to the end pads (Figure 19), the block frame to the towers (Figure 10), the handle and latches to their pads:

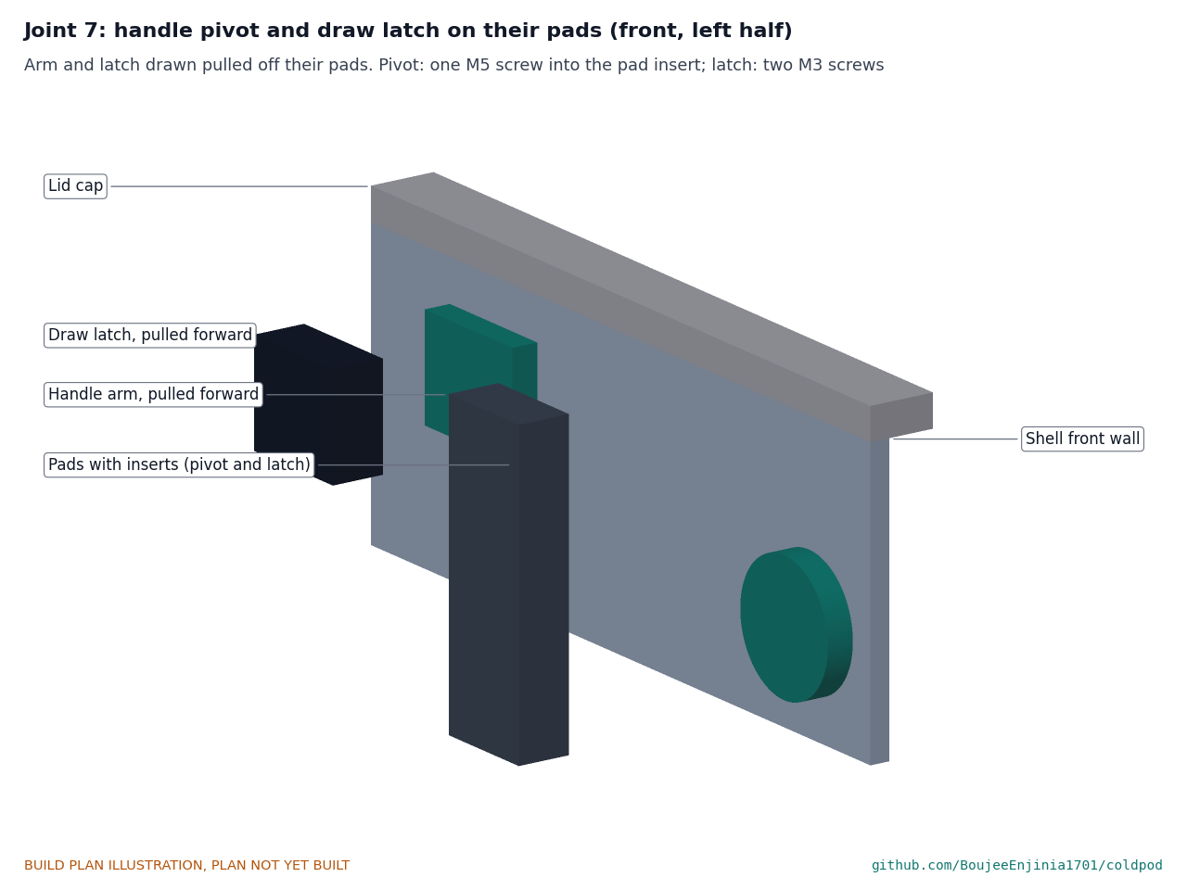
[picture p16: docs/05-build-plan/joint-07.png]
Figure 3. Joint 7: handle pivot and latch on their pads


*Figure 3. The handle arm and the latch drawn pulled off their pads. The pivot is one M5 screw into the pad's insert; the latch takes two M3 screws.*

**Check before moving on.** The inside is 255 x 190, square, within 0.5 mm. Every insert sits flush and square, and no insert has pushed through the inside of a wall.

### 3.2 Vacuum-insulated panels (bought to size)

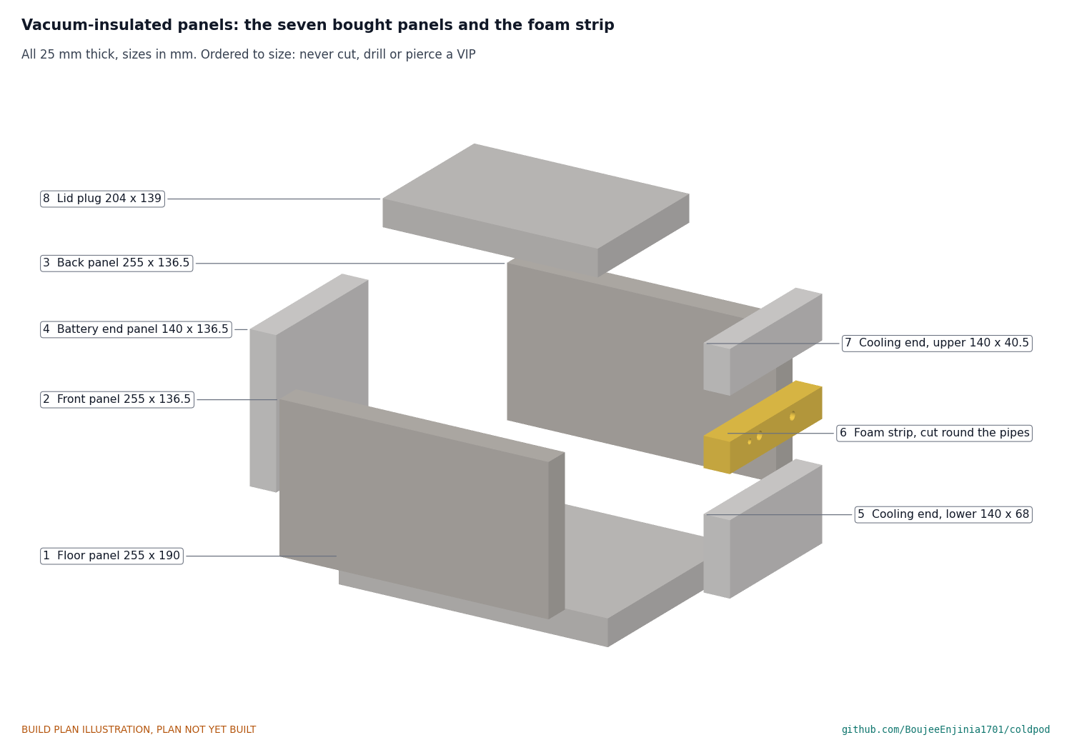
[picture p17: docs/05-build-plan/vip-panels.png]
Figure 4. The seven VIP panels and the foam strip


*Figure 4. The seven panels, all 25 mm thick, and the foam strip that fills the gap where the pipes cross.*

**What they are.** Fumed silica panels in metallized film, ordered to size from a VIP maker: floor 255 x 190; front and back 255 x 136.5 tall; left end 140 x 136.5; right end lower 140 x 68 and upper 140 x 40.5; lid plug 204 x 139. Order them to plus 0, minus 1 mm. Between the two right-end panels is a 28 mm strip of polyurethane foam, cut on the bench round the pipes and the cable (step 5).

**How they fit.** Butt jointed, edge to edge, on strips of acrylic foam tape: the floor on the shell floor, the front and back on the floor along the full length, the two ends between them. Store them flat in their packaging until step 1, away from tools.

**Check before moving on.** No panel has a soft spot or a wrinkled, puffy film (a sign it has lost its vacuum).

### 3.3 Evaporator can

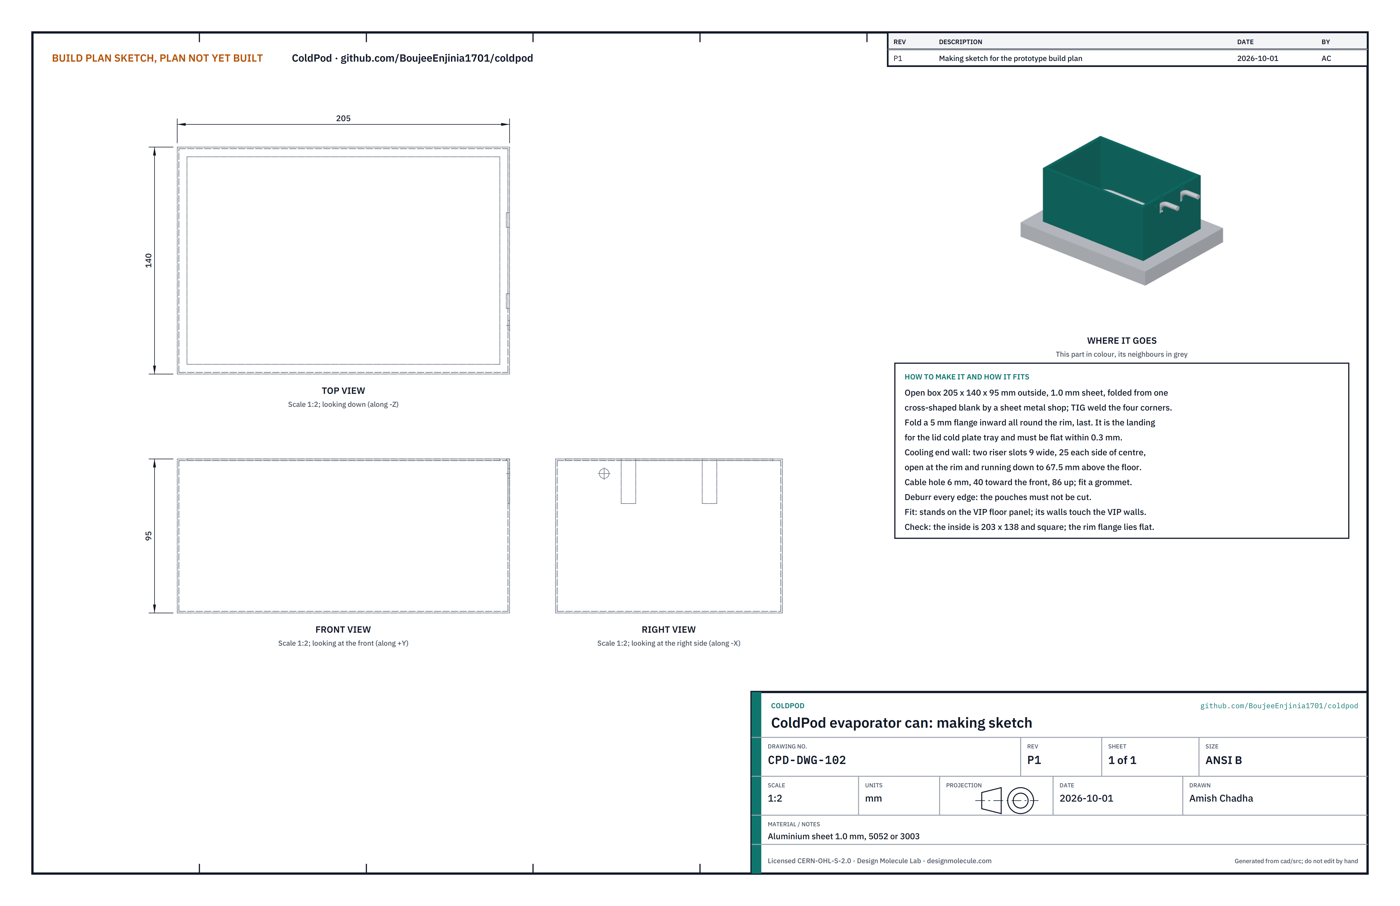
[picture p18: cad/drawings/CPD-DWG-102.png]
Figure 5. Making sketch of the evaporator can


*Figure 5. Evaporator can making sketch (CPD-DWG-102).*

**What it is and what it is made from.** The aluminium box that holds the PCM pouches and spreads the cold from the loop over the whole jacket. Aluminium sheet 1.0 mm, 5052 or 3003, 205 x 140 x 95 mm outside.

**How to make it.** Have a sheet metal shop do steps 1 to 3.

1. Fold an open box from one cross-shaped blank and TIG weld the four vertical corners.
2. In the right-hand wall, cut two slots 9 wide, 25 each side of the centre, open at the rim and running down to 67.5 above the floor; drill a 6 mm hole 40 toward the front and 86 up for the sensor cable.
3. Fold a 5 mm flange inward all round the rim, last. It must be flat within 0.3 mm: the lid tray lands on it.
4. Deburr every edge and fit a grommet in the cable hole; a sharp edge would cut a pouch.

**How it fits the parts next to it.** It stands on the VIP floor with its walls against the VIP walls. The loop lies in its bottom corner:

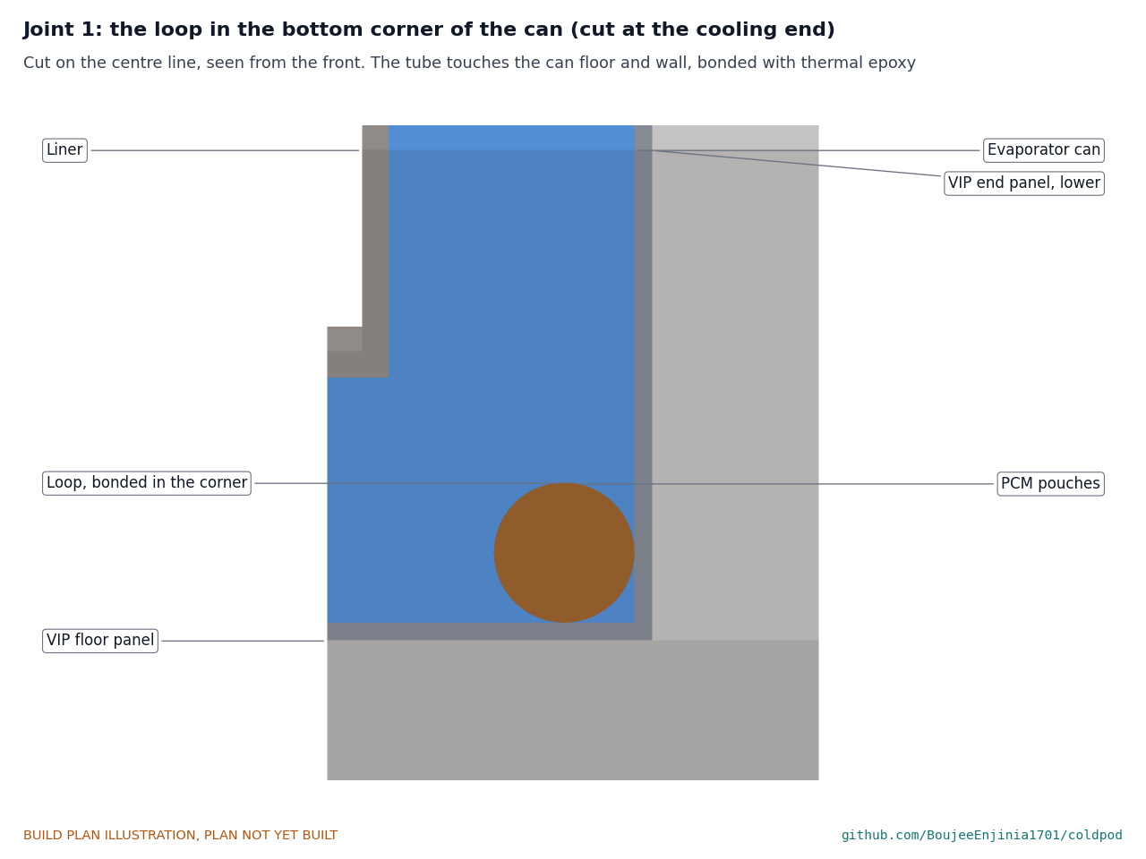
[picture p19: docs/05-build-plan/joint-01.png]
Figure 6. Joint 1: the loop in the corner of the can


*Figure 6. Cut on the centre line at the right-hand end. The tube touches the can floor and wall and is bonded along its length.*

**Check before moving on.** Inside 203 x 138, square; the rim flange lies flat on a table.

### 3.4 Loop thermosiphon

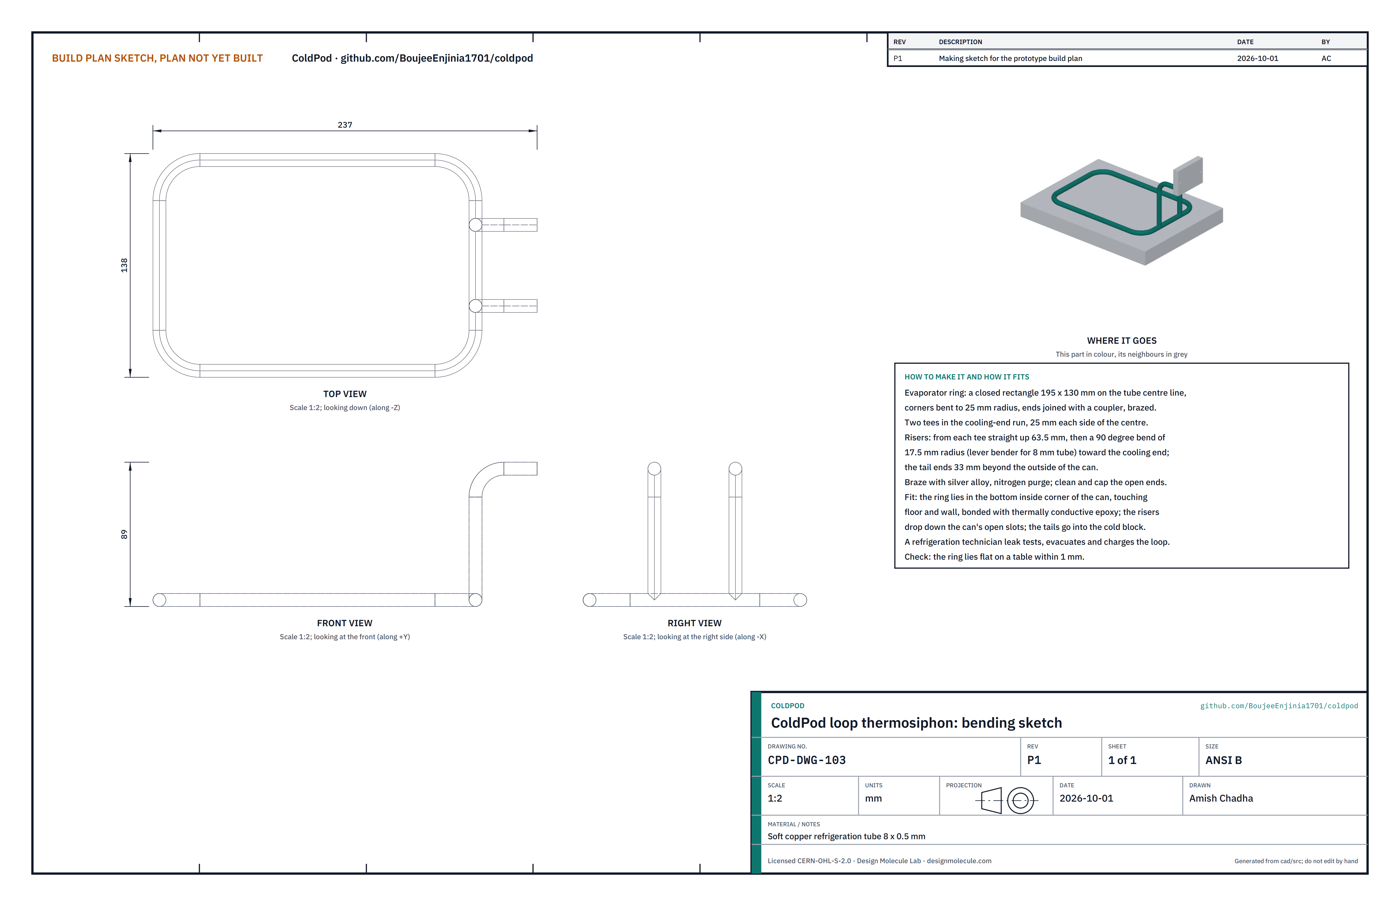
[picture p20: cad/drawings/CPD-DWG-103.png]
Figure 7. Bending sketch of the loop thermosiphon


*Figure 7. Loop thermosiphon bending sketch (CPD-DWG-103).*

**What it is and what it is made from.** The one-way heat path: a sealed copper circuit in which the working fluid (R-134a) boils in the ring at the bottom of the can, rises as vapour, condenses in the cold block and runs back down as liquid. Soft copper refrigeration tube 8 x 0.5 mm.

**How to make it.** Bending is bench work; brazing, leak testing and charging are for a refrigeration technician (safety stops S1 and S2).

1. Bend the ring: a rectangle 195 x 130 on the tube centre line with 25 mm corner bends, the two ends joined with a coupler in the middle of the left-hand run.
2. Fit two tees in the right-hand run, 25 each side of the centre.
3. Bend two risers: straight up 63.5 from the tee, then a 90° bend of 17.5 mm radius (a lever bender for 8 mm tube) toward the right; the tail ends 33 beyond the outside of the can.
4. Braze the coupler, tees and risers with silver alloy under a nitrogen purge. Cap the open tails.
5. Lower the ring into the can (step 2) and bond it into the bottom corner with thermally conductive epoxy, touching floor and wall all round.

**How it fits the parts next to it.**

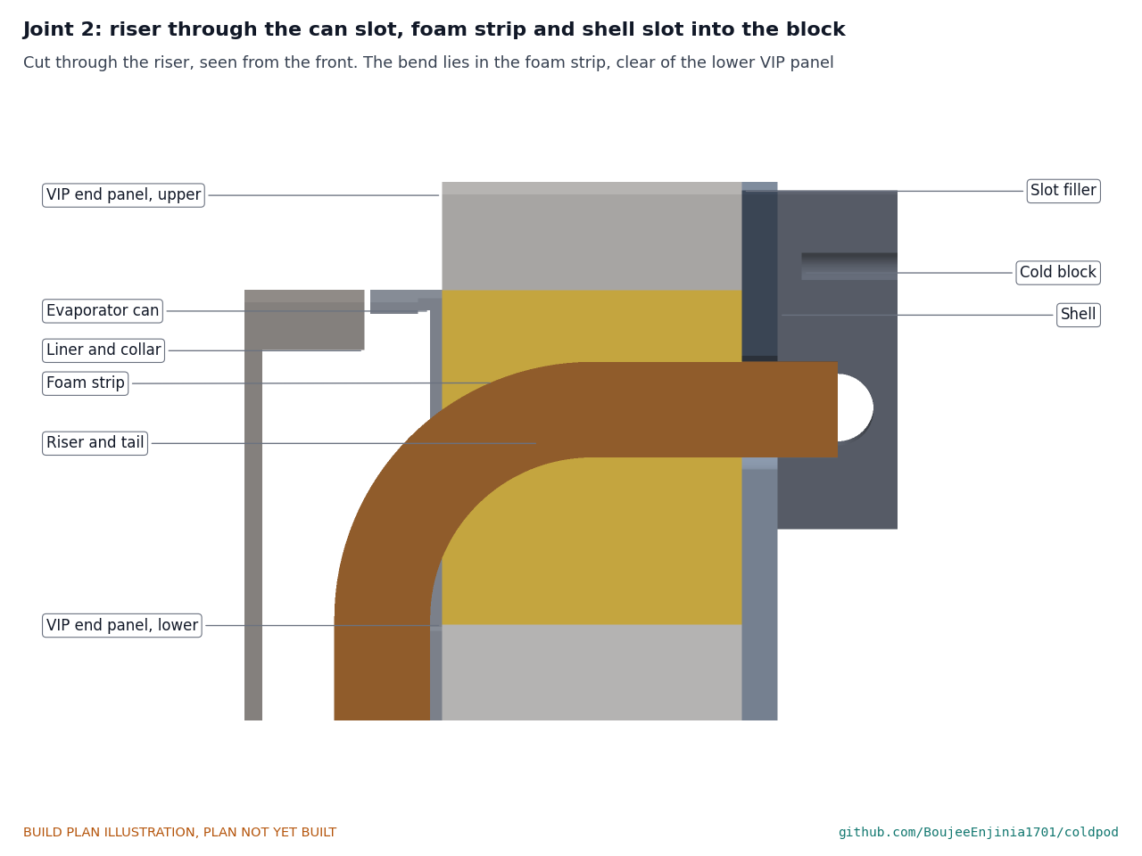
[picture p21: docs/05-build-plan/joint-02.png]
Figure 8. Joint 2: riser through the can slot, foam strip and shell slot


*Figure 8. Cut through a riser, seen from the front. The bend runs through the can's slot into the foam strip, clear of the lower VIP panel, and the tail enters the cold block's socket.*

The ring sits in the can's corner; each riser drops down its slot in the can and, later, its slot in the shell. The tails end in the cold block's sockets.

**Check before moving on.** The ring lies flat on a table within 1 mm; both tails are level, 50 apart, and stand 33 beyond the can.

### 3.5 Cold block

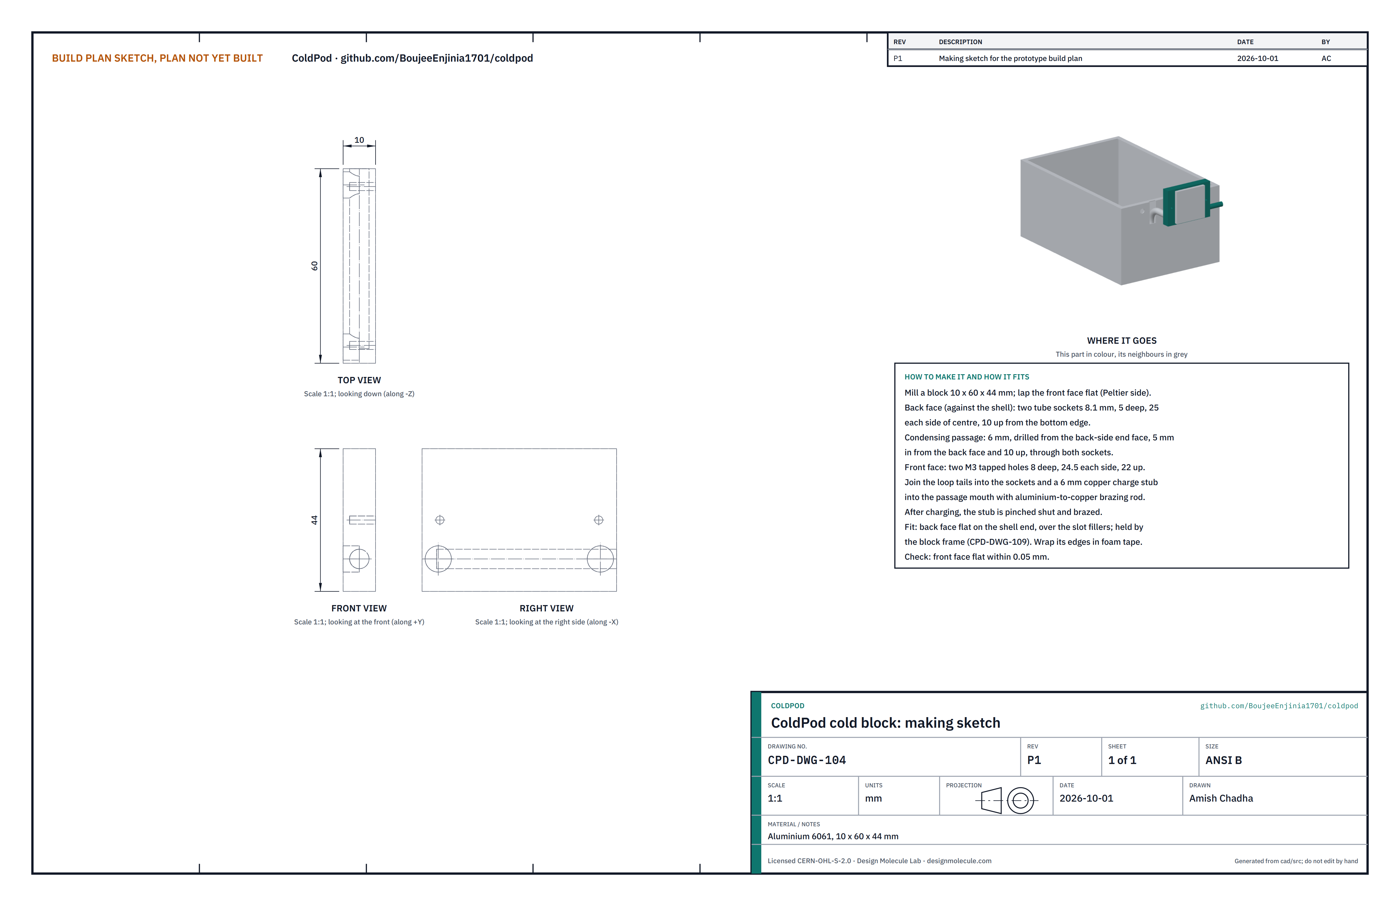
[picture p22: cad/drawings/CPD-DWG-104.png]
Figure 9. Making sketch of the cold block


*Figure 9. Cold block making sketch (CPD-DWG-104).*

**What it is and what it is made from.** The condenser of the loop and the cold face for the Peltier module. Aluminium 6061, 10 x 60 x 44 mm.

**How to make it.**

1. Mill the block square; lap the front face (the Peltier side) flat within 0.05 mm.
2. In the back face, drill two tube sockets 8.1 mm, 5 deep, 25 each side of the centre, 10 up from the bottom edge.
3. From the back-side end face, drill a 6 mm passage 5 mm in from the back face and 10 up, through both sockets.
4. In the front face, drill and tap two M3 holes 8 deep, 24.5 each side of the centre, 22 up.
5. The technician brazes the loop tails into the sockets and a 6 mm copper charge stub into the passage mouth with aluminium-to-copper brazing rod, leak tests the loop with dry nitrogen, evacuates and charges it, then pinches the stub shut and brazes the end (step 3).

**How it fits the parts next to it.**

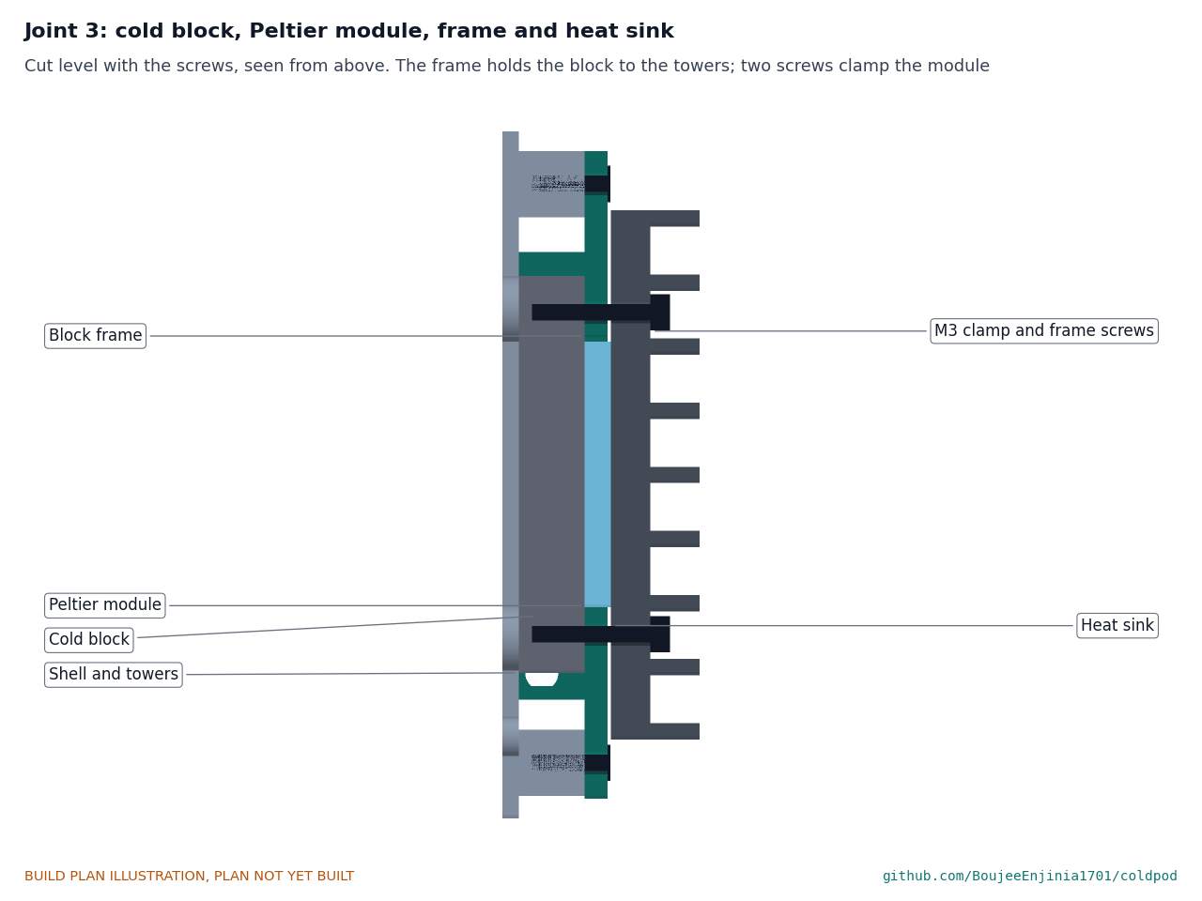
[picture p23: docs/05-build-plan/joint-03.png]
Figure 10. Joint 3: cold block, Peltier module, frame and heat sink


*Figure 10. Cut level with the screws, seen from above. The frame holds the block to the shell towers; two screws through the heat sink clamp the module.*

The back face sits flat on the right-hand end of the shell, over the slot fillers. The printed block frame (section 3.10) holds it there. The Peltier module sits on the front face, cold side to the block, and the heat sink on the module. Wrap the block's edges and the tails in closed-cell foam tape after assembly, leaving the module face clear.

**Check before moving on.** The front face is flat; the charged loop holds its charge for 24 hours with no change in the technician's gauge reading.

### 3.6 Slot fillers (make 3)

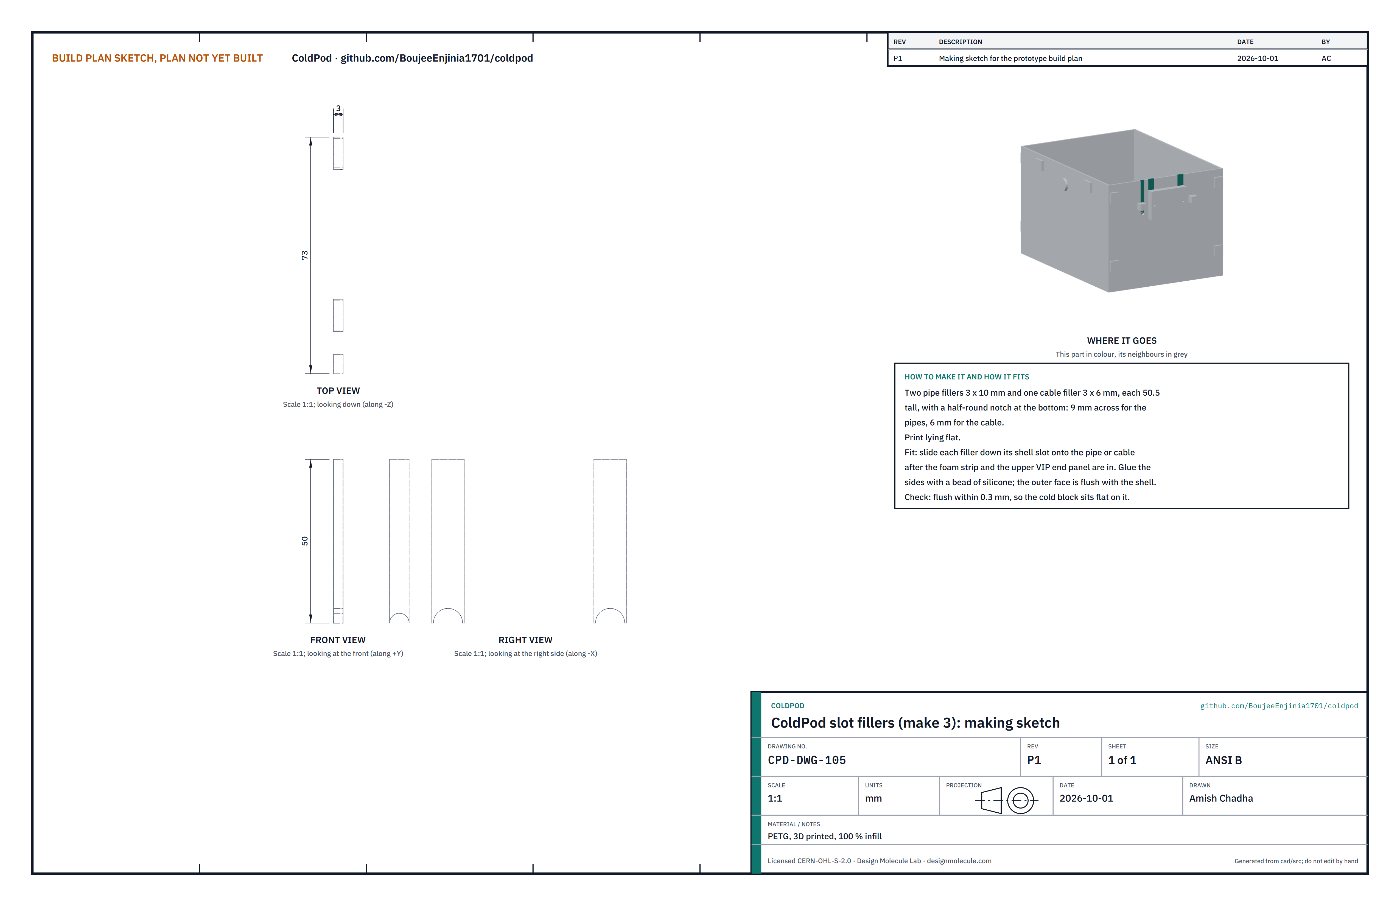
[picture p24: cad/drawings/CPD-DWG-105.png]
Figure 11. Making sketch of the slot fillers


*Figure 11. Slot fillers making sketch (CPD-DWG-105).*

**What they are and what they are made from.** Strips that close the shell's three slots above the pipes and the cable. PETG, printed solid.

**How to make them.** Print two pipe fillers 3 x 10 and one cable filler 3 x 6, each 50.5 tall, lying flat. Each has a half-round notch at the bottom: 9 across for a pipe, 6 for the cable.

**How they fit.** After the foam strip and the upper VIP panel are in, each slides down its slot onto its pipe or cable, with a bead of silicone on both sides (Figure 8). The outer face is flush with the shell, because the cold block sits on it.

**Check before moving on.** Flush within 0.3 mm.

### 3.7 Liner

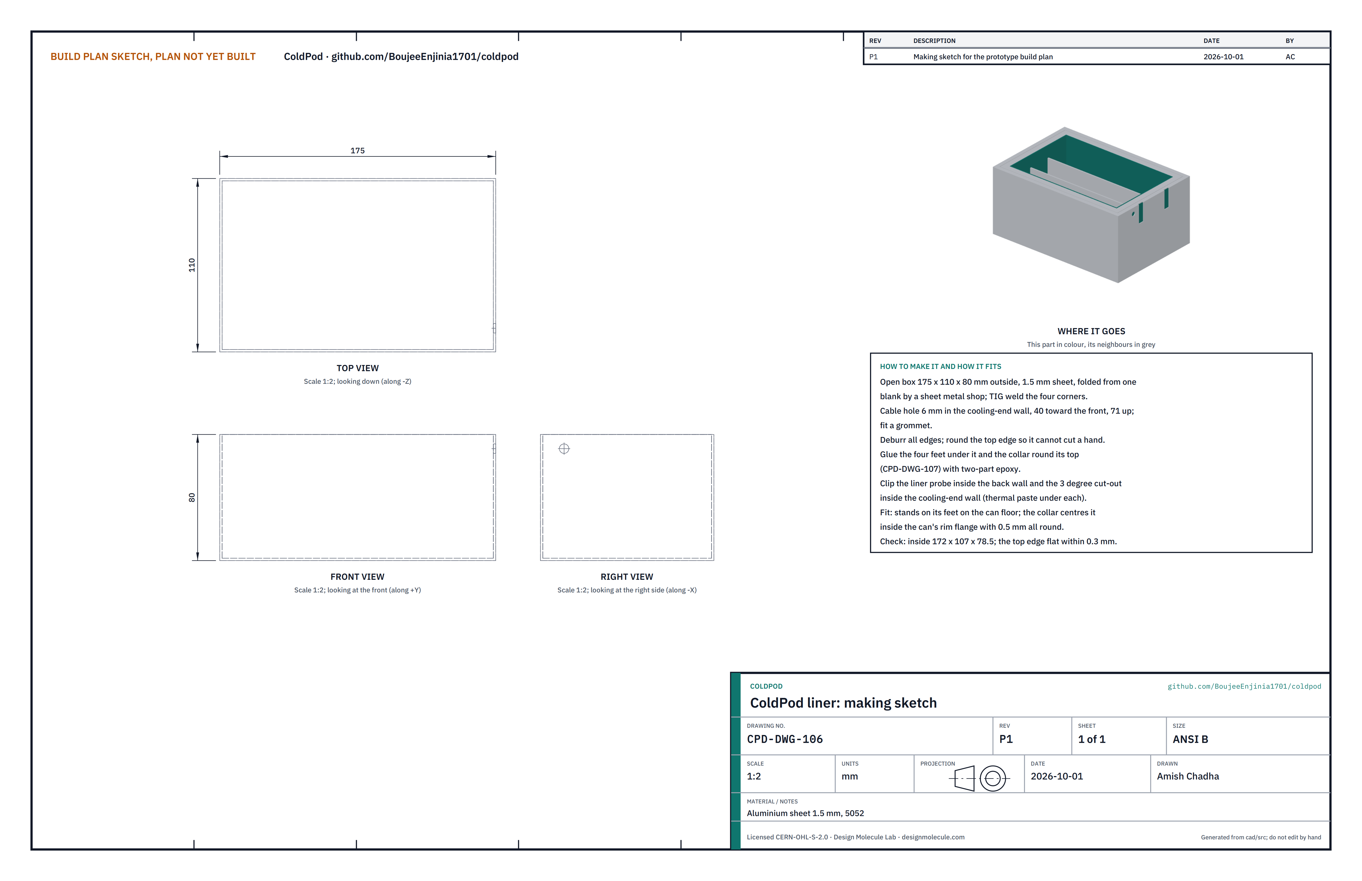
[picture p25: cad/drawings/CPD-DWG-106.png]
Figure 12. Making sketch of the liner


*Figure 12. Liner making sketch (CPD-DWG-106).*

**What it is and what it is made from.** The aluminium box the payload sits in; it spreads the cold evenly round the pens. Aluminium sheet 1.5 mm, 5052, 175 x 110 x 80 mm outside.

**How to make it.**

1. Have a sheet metal shop fold an open box from one blank and TIG weld the four corners.
2. Drill a 6 mm hole in the right-hand wall, 40 toward the front and 71 up, and fit a grommet.
3. Deburr all edges and round the top edge so it cannot cut a hand.
4. Clip the liner probe to the inside of the back wall and the 3 °C cut-out to the inside of the right-hand wall, each on a thin layer of thermal paste. Run their leads to the grommet and join them to the sensor cable.

**How it fits the parts next to it.** It stands on four printed feet on the can floor and is centred by a printed collar (section 3.8), never touching the can. The sensor cable leaves through the grommet, crosses the jacket and leaves the can through its own grommet.

**Check before moving on.** Inside 172 x 107 x 78.5; the top edge flat within 0.3 mm; both sensors and the cut-out read correctly on a meter.

### 3.8 Liner feet (make 4) and collar

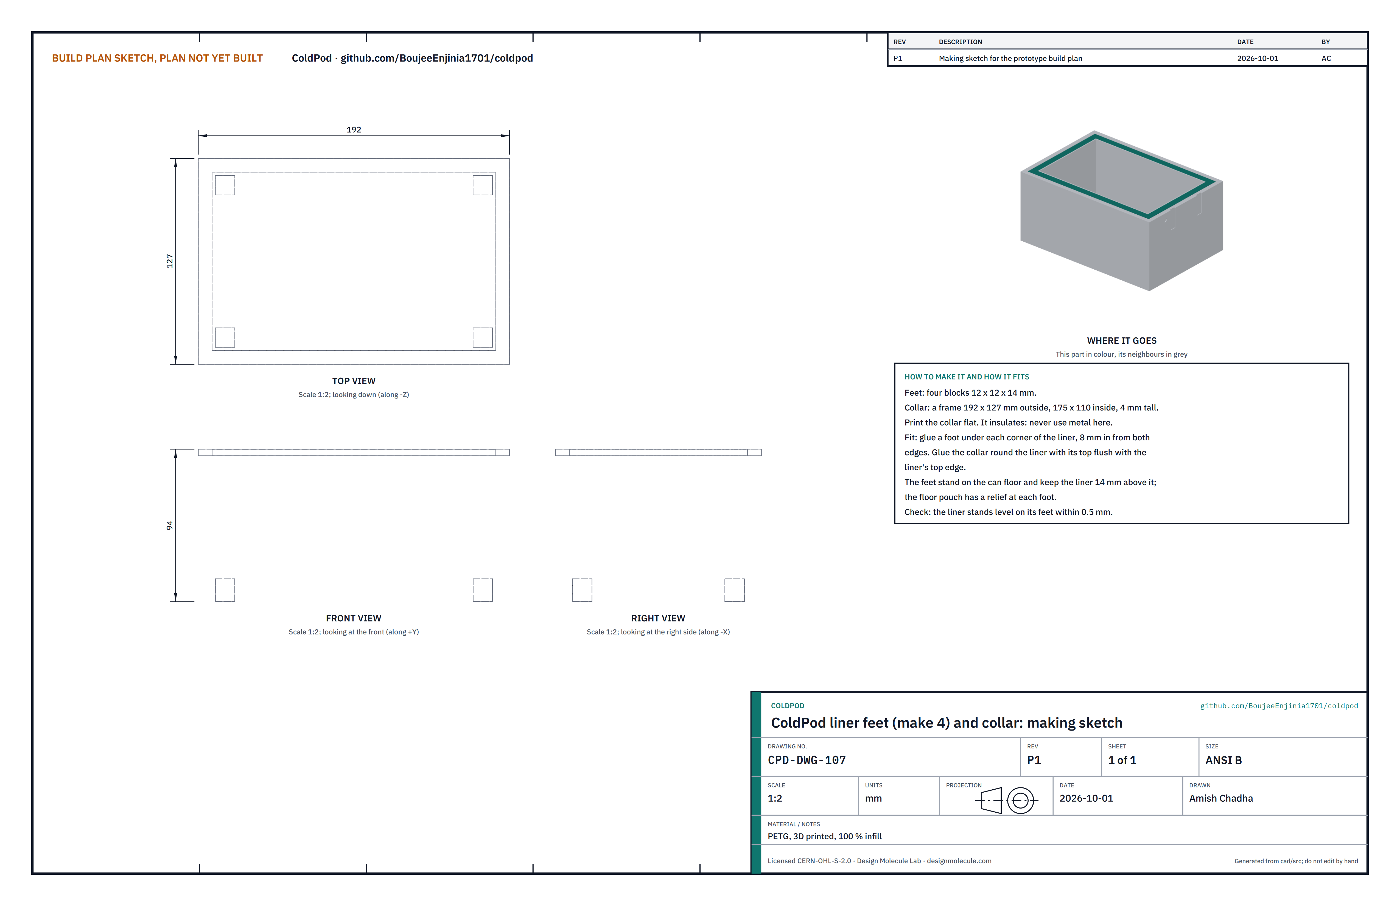
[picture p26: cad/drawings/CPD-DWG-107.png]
Figure 13. Making sketch of the liner feet and collar


*Figure 13. Liner feet and collar making sketch (CPD-DWG-107).*

**What they are and what they are made from.** Plastic spacers that hold the liner in the middle of the can without a metal path between them. PETG, printed solid.

**How to make them.** Print four feet 12 x 12 x 14 and a collar frame 192 x 127 outside, 175 x 110 inside, 4 tall, lying flat.

**How they fit the parts next to them.**

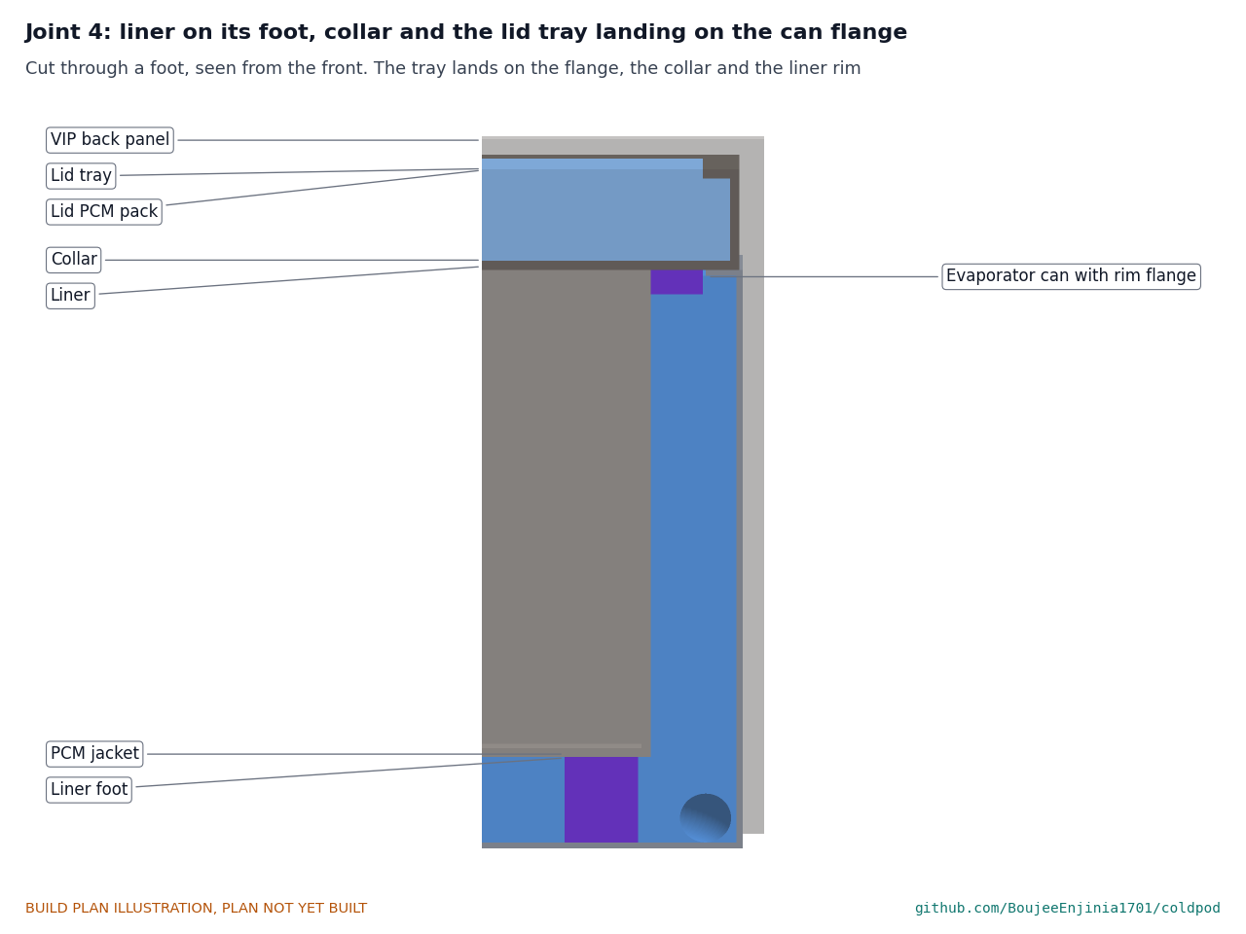
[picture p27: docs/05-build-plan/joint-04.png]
Figure 14. Joint 4: liner foot, collar and the lid tray landing


*Figure 14. Cut through a foot, seen from the front. The foot keeps the liner 14 mm above the can floor; the collar centres it inside the can's rim flange; the lid tray lands on the flange.*

Glue a foot under each corner of the liner, 8 in from both edges, and the collar round the liner with its top flush with the liner's top edge, all with two-part epoxy. The collar clears the can's rim flange by 0.5 all round.

**Check before moving on.** The liner stands level on its feet within 0.5 mm.

### 3.9 Payload rack

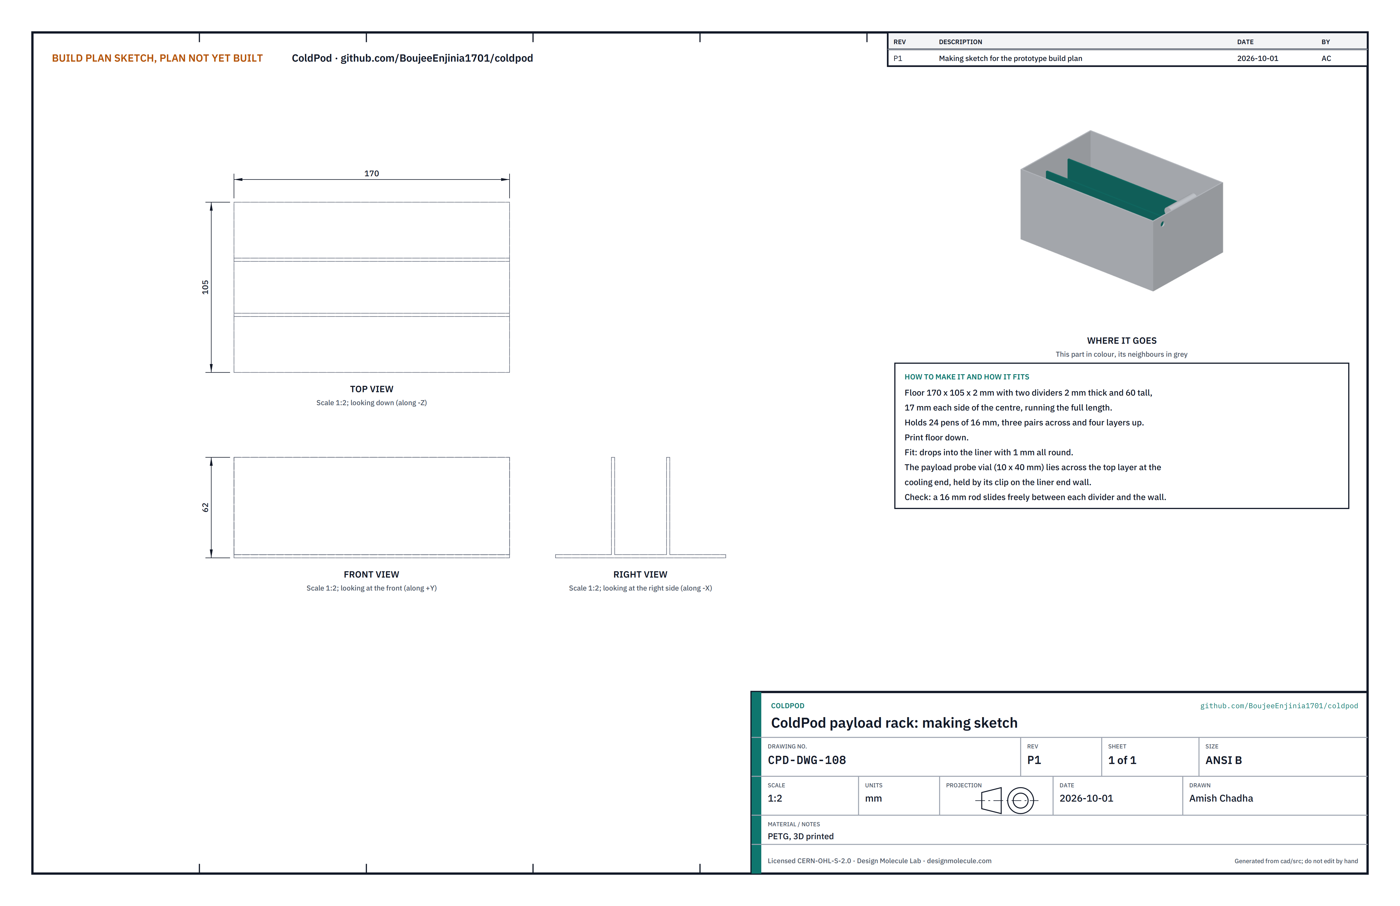
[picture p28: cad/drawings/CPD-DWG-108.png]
Figure 15. Making sketch of the payload rack


*Figure 15. Payload rack making sketch (CPD-DWG-108). The inset shows the payload probe vial lying across the top at the right-hand end.*

**What it is and what it is made from.** A printed floor with two dividers that holds 24 pens of 16 mm, three pairs across and four layers up. PETG.

**How to make it.** Print floor down: a floor 170 x 105 x 2 with two dividers 2 thick and 60 tall, 17 each side of the centre, running the full length.

**How it fits the parts next to it.** It drops into the liner with 1 mm all round. The payload probe, a 10 x 40 mm glycol-buffered vial with a digital sensor, lies across the top layer of pens at the right-hand end, held by a printed clip on the liner's end wall, 1.8 mm above the pens and 1.5 mm below the lid tray.

**Check before moving on.** A 16 mm rod slides freely between each divider and the wall.

### 3.10 Block frame and drip tray

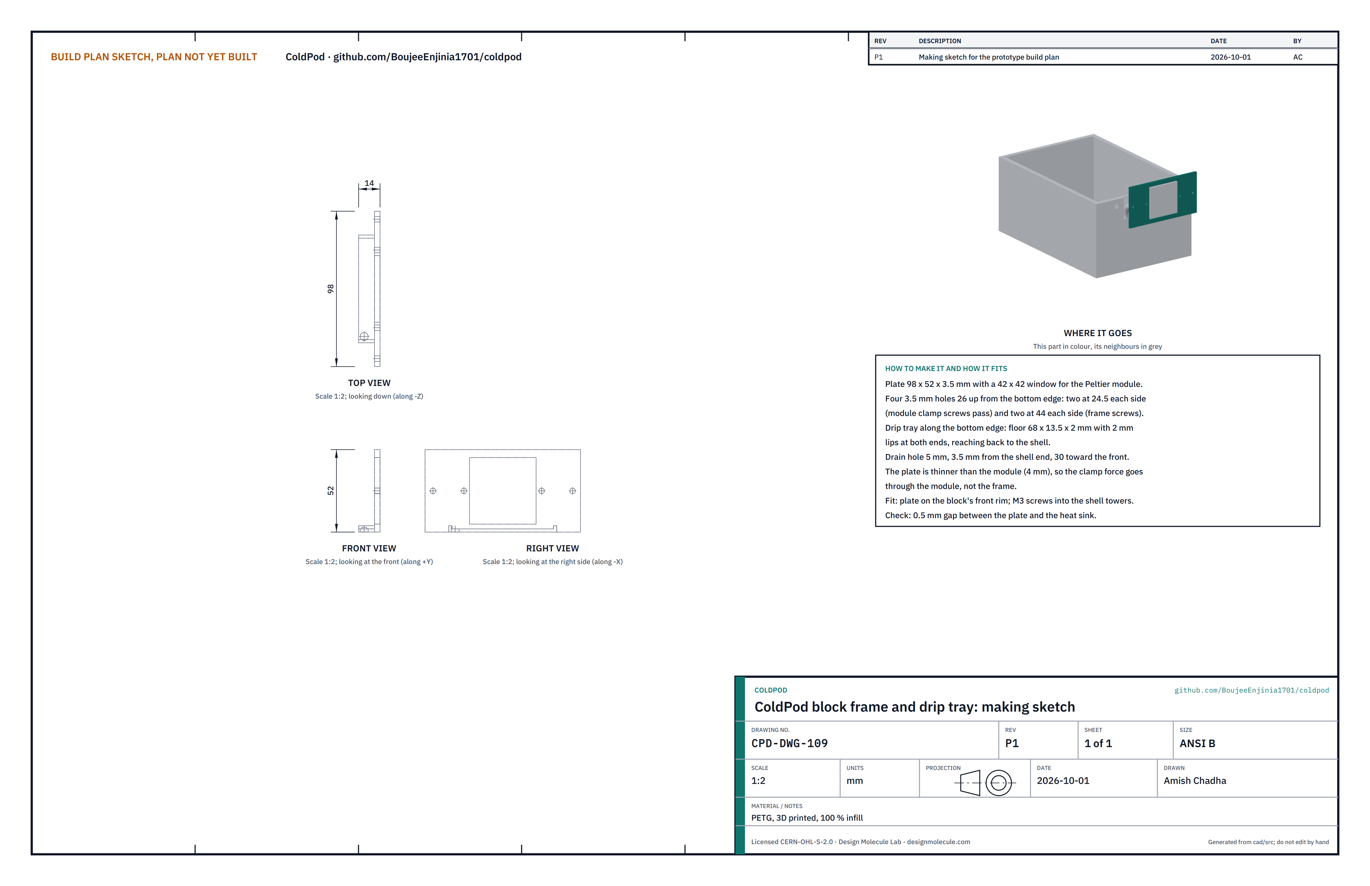
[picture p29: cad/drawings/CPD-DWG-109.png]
Figure 16. Making sketch of the block frame and drip tray


*Figure 16. Block frame and drip tray making sketch (CPD-DWG-109).*

**What it is and what it is made from.** A printed frame that holds the cold block against the shell and catches the water that condenses on it. PETG, printed solid.

**How to make it.** Print a plate 98 x 52 x 3.5 with a 42 x 42 window for the Peltier module, four 3.5 mm holes 26 up from its bottom edge (two at 24.5 each side of the centre for the clamp screws to pass, two at 44 each side for the frame screws) and, along the bottom edge, a drip tray 68 wide reaching back 13.5 to the shell, with 2 mm lips at both ends and a 5 mm drain hole near the shell, 30 toward the front.

**How it fits the parts next to it.** The plate rests on the block's front face round the module and is screwed to the shell's two towers with M3 screws. It is 0.5 thinner than the module, so the clamp force goes through the module, and it stays 0.5 clear of the hot heat sink. A 4 mm drain tube runs from the tray's hole down through the floor of the cooling head:

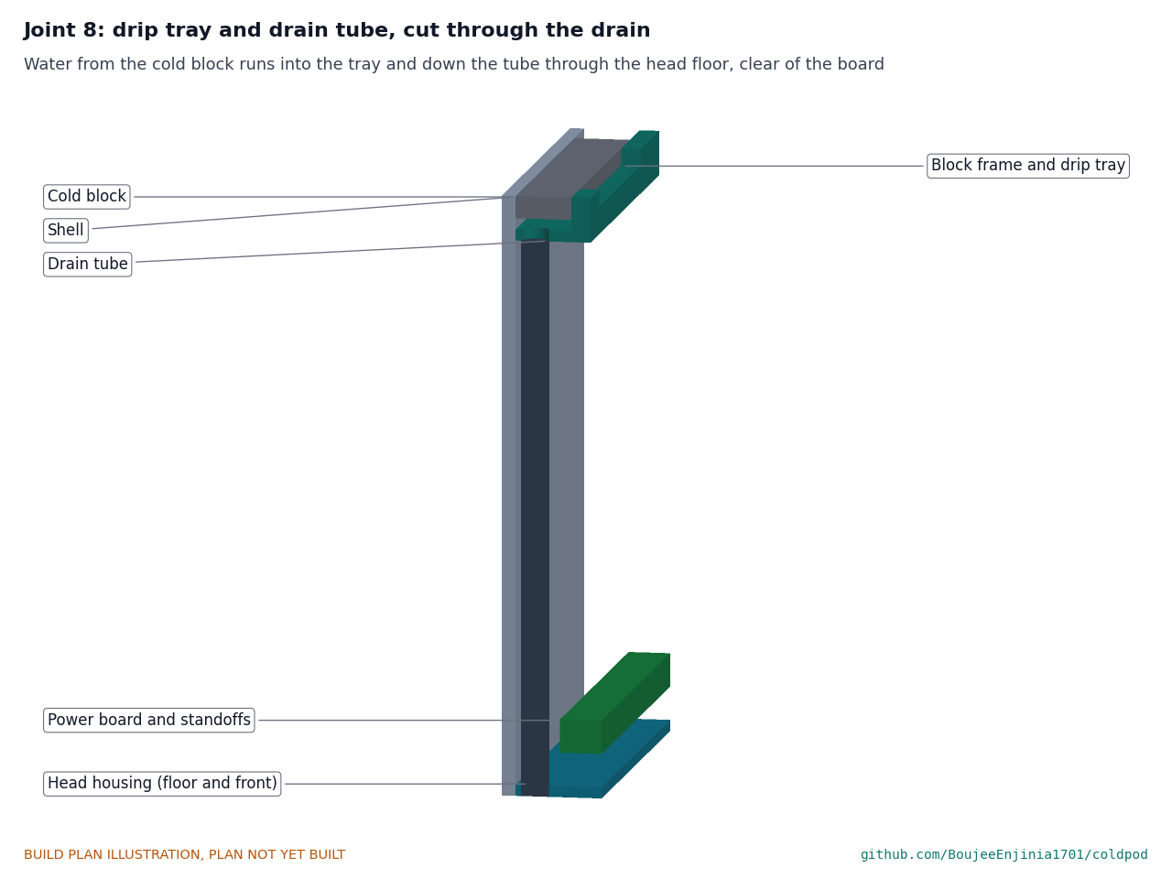
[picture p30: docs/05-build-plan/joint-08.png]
Figure 17. Joint 8: drip tray and drain tube


*Figure 17. Cut through the drain. Water from the block runs down the tube and out through the head floor, clear of the power board.*

**Check before moving on.** Water poured into the tray runs out of the tube.

### 3.11 Cooling head housing

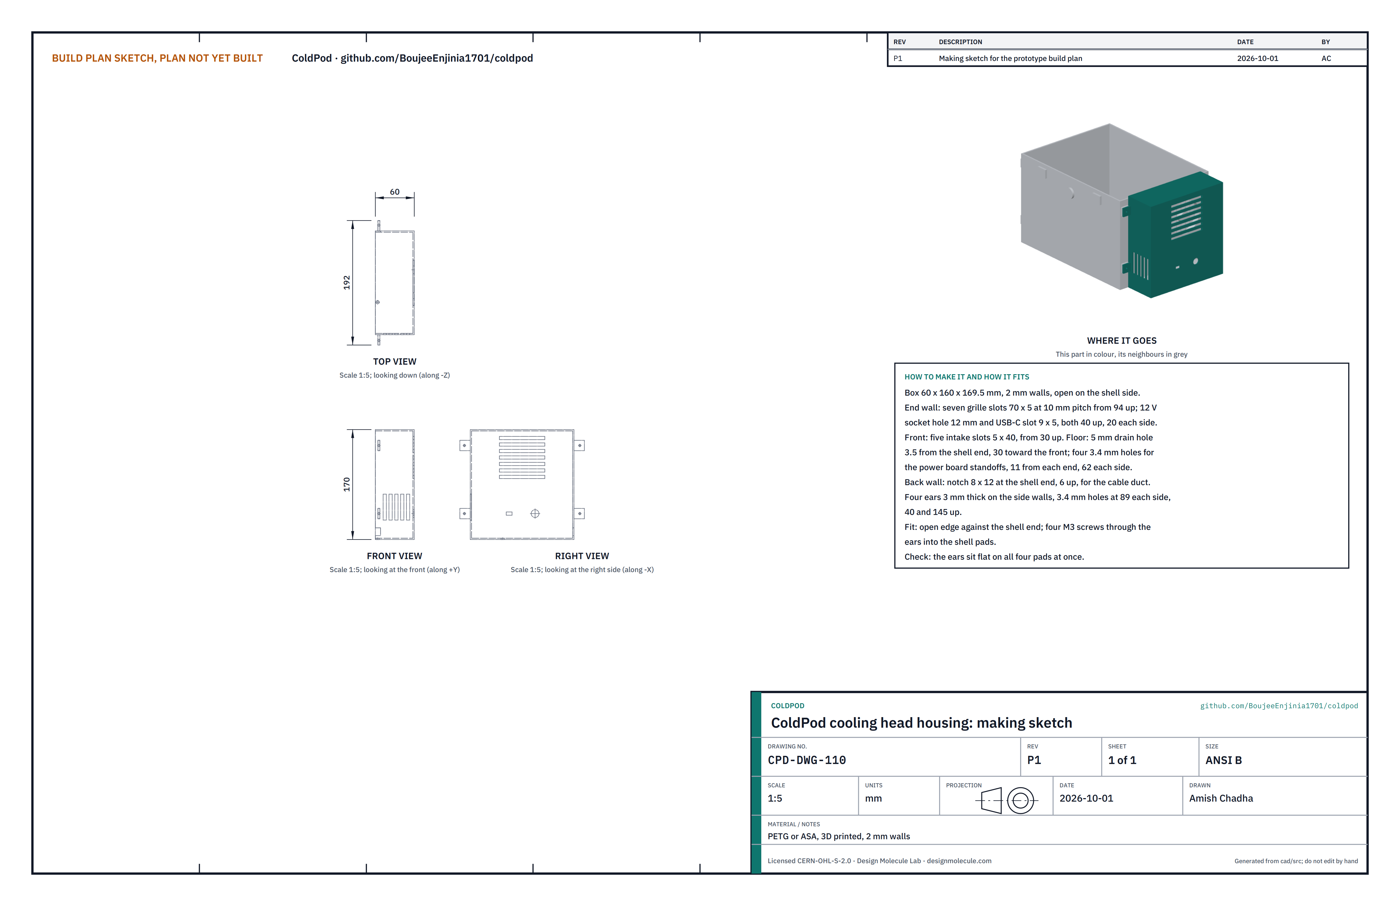
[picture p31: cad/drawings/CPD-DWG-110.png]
Figure 18. Making sketch of the cooling head housing


*Figure 18. Cooling head housing making sketch (CPD-DWG-110).*

**What it is and what it is made from.** The vented printed cover over the Peltier stack, the fan and the power board. PETG or ASA, 60 x 160 x 169.5 mm, 2 mm walls, open on the shell side.

**How to make it.**

1. Print it open side down.
2. Check the end wall: seven grille slots 70 x 5 at 10 pitch from 94 up; a 12 mm hole for the 12 V socket, 20 toward the back, and a 9 x 5 slot for the USB-C socket, 20 toward the front, both 40 up.
3. Check the front wall: five intake slots 5 x 40 from 30 up.
4. Check the floor: a 5 mm drain hole 3.5 from the shell end, 30 toward the front; four 3.4 mm holes for the power board standoffs, 11 from each end, 62 each side.
5. Check the back wall: a notch 8 x 12 at the shell end, 6 up, for the cable duct; and the four ears with 3.4 mm holes, 89 each side of the centre, 40 and 145 up.

**How it fits the parts next to it.**

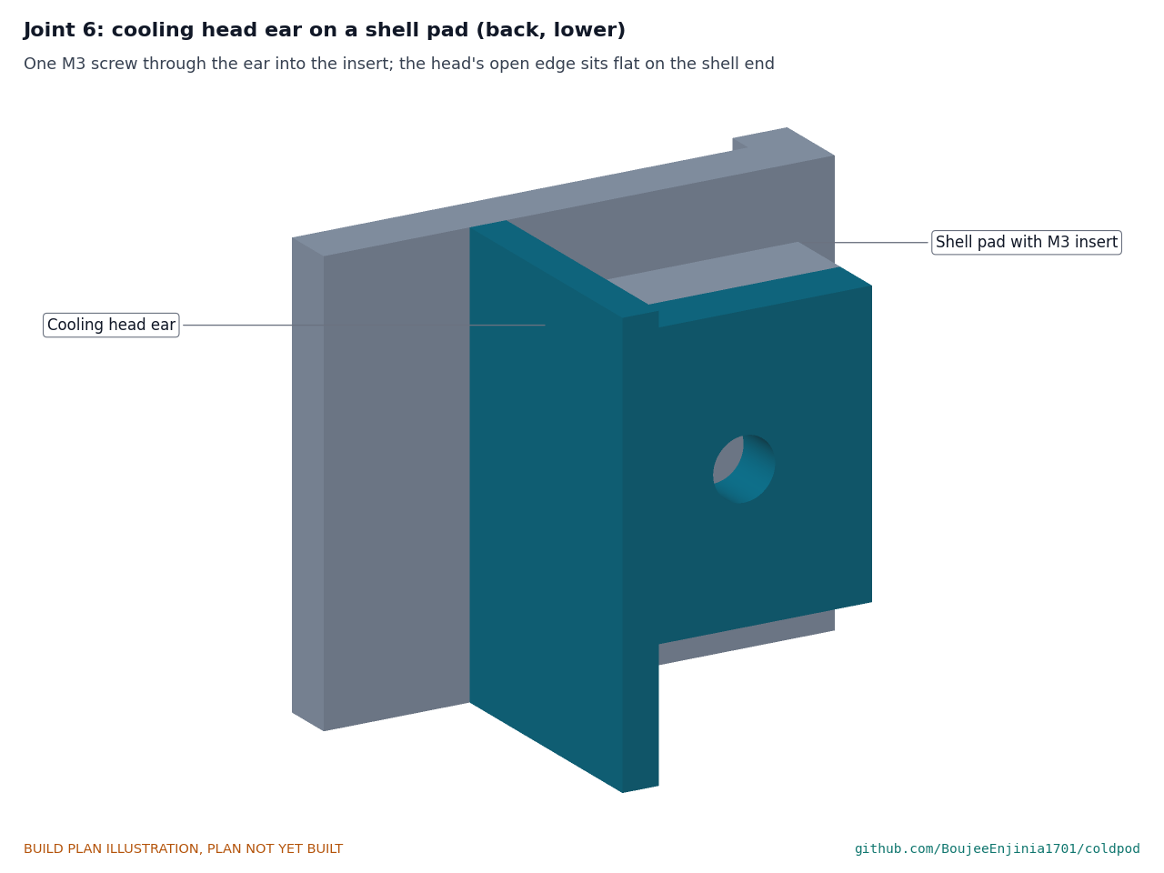
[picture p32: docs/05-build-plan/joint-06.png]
Figure 19. Joint 6: a cooling head ear on a shell pad


*Figure 19. One M3 screw through each ear into the pad's insert; the open edge of the housing sits flat on the shell end.*

Inside, the power board stands on four M3 standoffs, the inlets fit the end wall, and the ambient sensor's vented cap sits on the outside of the front wall above the intake slots. A reed switch taped inside the housing's top, 5 from the shell end, faces a magnet in the lid cap's edge to sense an open lid.

**Check before moving on.** The four ears sit flat on the four pads at once.

### 3.12 Wiring

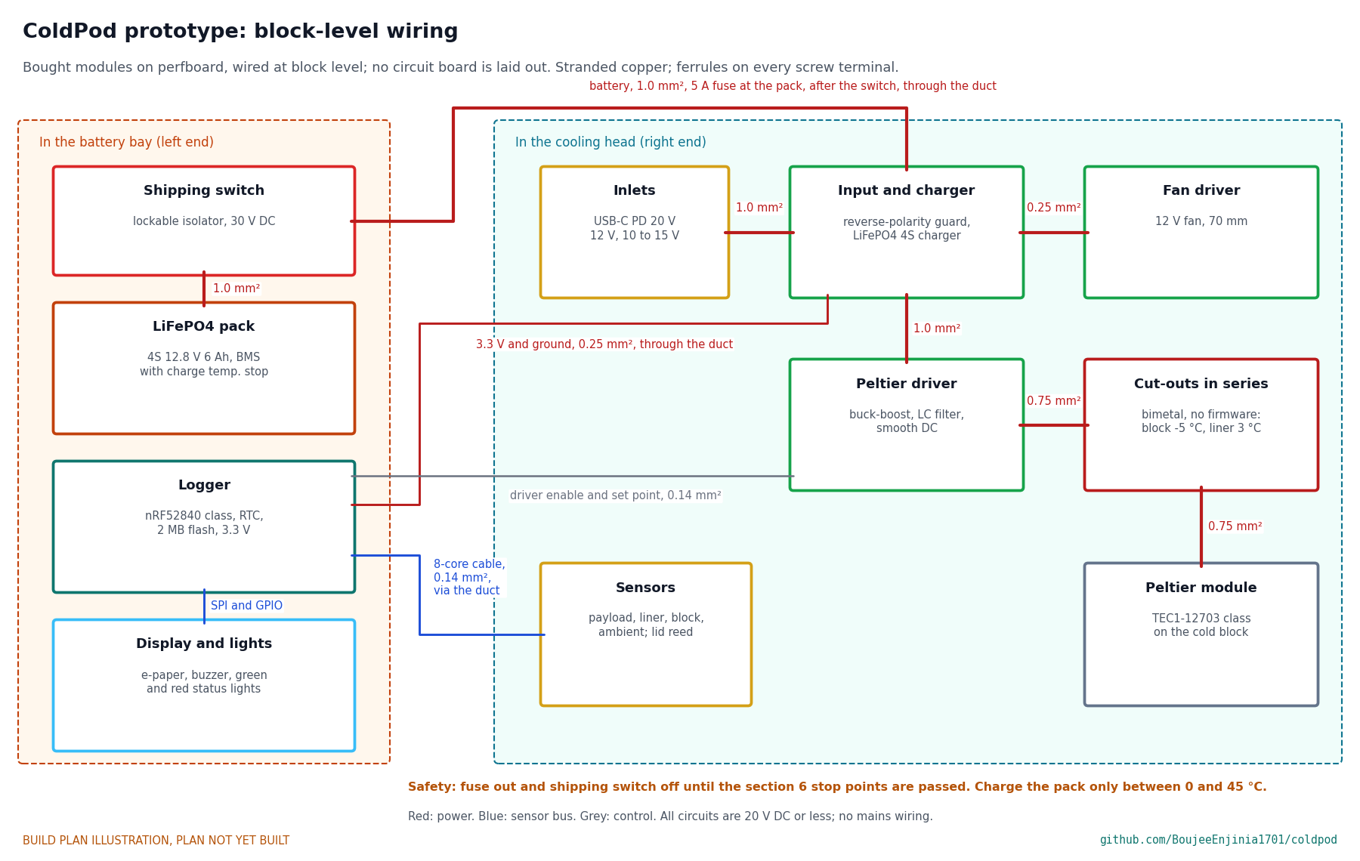
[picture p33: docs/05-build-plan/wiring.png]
Figure 20. Block-level wiring


*Figure 20. Block-level wiring with wire sizes. No circuit board is laid out; bought modules on perfboard stand in for the power board.*

*Table 2. Modules.*

| Module | What to buy |
| --- | --- |
| Input stage | USB-C PD sink module set to 20 V, 45 W or more; 12 V input with reverse-polarity protection, 10 to 15 V |
| Charger | Four-cell lithium iron phosphate charger, about 12 W, charge stop at 14.4 V |
| Peltier driver | Buck-boost converter that can feed the module from 10 to 20 V input, with an LC output filter for smooth DC and an enable and set point input |
| Fan driver | Switched 12 V output for the 70 mm fan |
| Cut-outs | Two normally closed bimetal thermostats: one on the cold block opening at -5 °C, one on the liner opening at 3 °C |
| Logger | nRF52840-class module with a real-time clock and 2 MB of flash, 3.3 V |
| Sensors | Glycol-buffered payload probe, liner probe, cold-block probe and ambient sensor, digital, ±0.5 °C or better |
| Display and lights | 2.13 in e-paper, buzzer, one green and one red status light |
| Shipping switch | Panel-mount rotary battery isolator for a 10 mm hole, rated 30 V DC and 10 A or more, with a lockable off position |

Wire it like this, with stranded copper and a ferrule on every screw terminal:

1. Inlets to the input stage: 1.0 mm² (18 AWG).
2. Input stage to the Peltier driver: 1.0 mm².
3. Peltier driver through the cold-block cut-out and then the liner cut-out to the module: 0.75 mm² (20 AWG). The two cut-outs are in series in the module supply and work without any firmware.
4. Fan driver to the fan: 0.25 mm² (24 AWG).
5. Battery pack through the shipping switch, then the 5 A fuse at the pack, to the charger: 1.0 mm², along the cable duct. The switch cuts the pack's positive lead, so with it off nothing in the box is live.
6. 3.3 V and ground from the power board to the logger: 0.25 mm², along the duct.
7. Sensor cable (eight cores, 0.14 mm²) from the cavity to the logger, along the duct; the driver enable and set point from the logger back to the driver in the same run.
8. Logger to the display and alarm: the display's own ribbon, and 0.25 mm² for the buzzer and the two status lights.

Conformal-coat the power board after the wiring checks pass: water condenses in the cooling head.

**Check before moving on.** Every wire continues end to end and is labelled; with the battery fuse out, no rail reads short to ground; with the shipping switch off and the fuse in, the board reads no voltage; each cut-out reads closed at room temperature and open when chilled in a bag of ice water (it opens at 3 °C; the block's at -5 °C needs a freezer).

### 3.13 Cell cradle

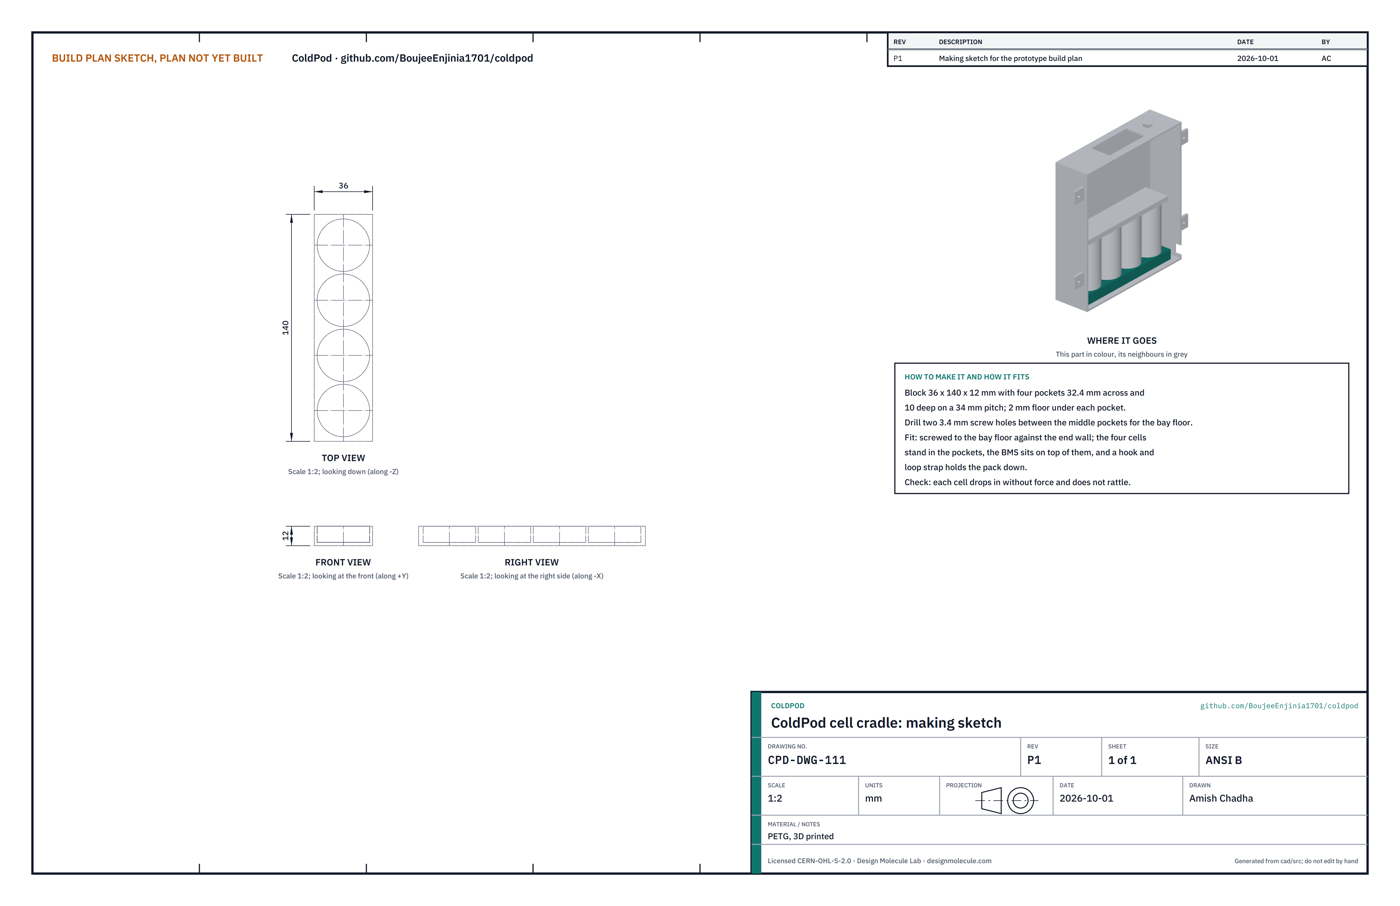
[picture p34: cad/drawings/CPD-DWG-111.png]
Figure 21. Making sketch of the cell cradle


*Figure 21. Cell cradle making sketch (CPD-DWG-111).*

**What it is and what it is made from.** A printed block that holds the four 32700 cells upright in the battery bay. PETG.

**How to make it.** Print a block 36 x 140 x 12 with four pockets 32.4 across and 10 deep on a 34 pitch, 2 mm floor under each. Drill two 3.4 mm screw holes between the middle pockets.

**How it fits the parts next to it.** Screwed to the bay floor against its end wall. The cells stand in the pockets, the battery management board sits on top of them, and a hook-and-loop strap holds the pack down.

**Check before moving on.** Each cell drops in without force and does not rattle.

### 3.14 Battery bay housing

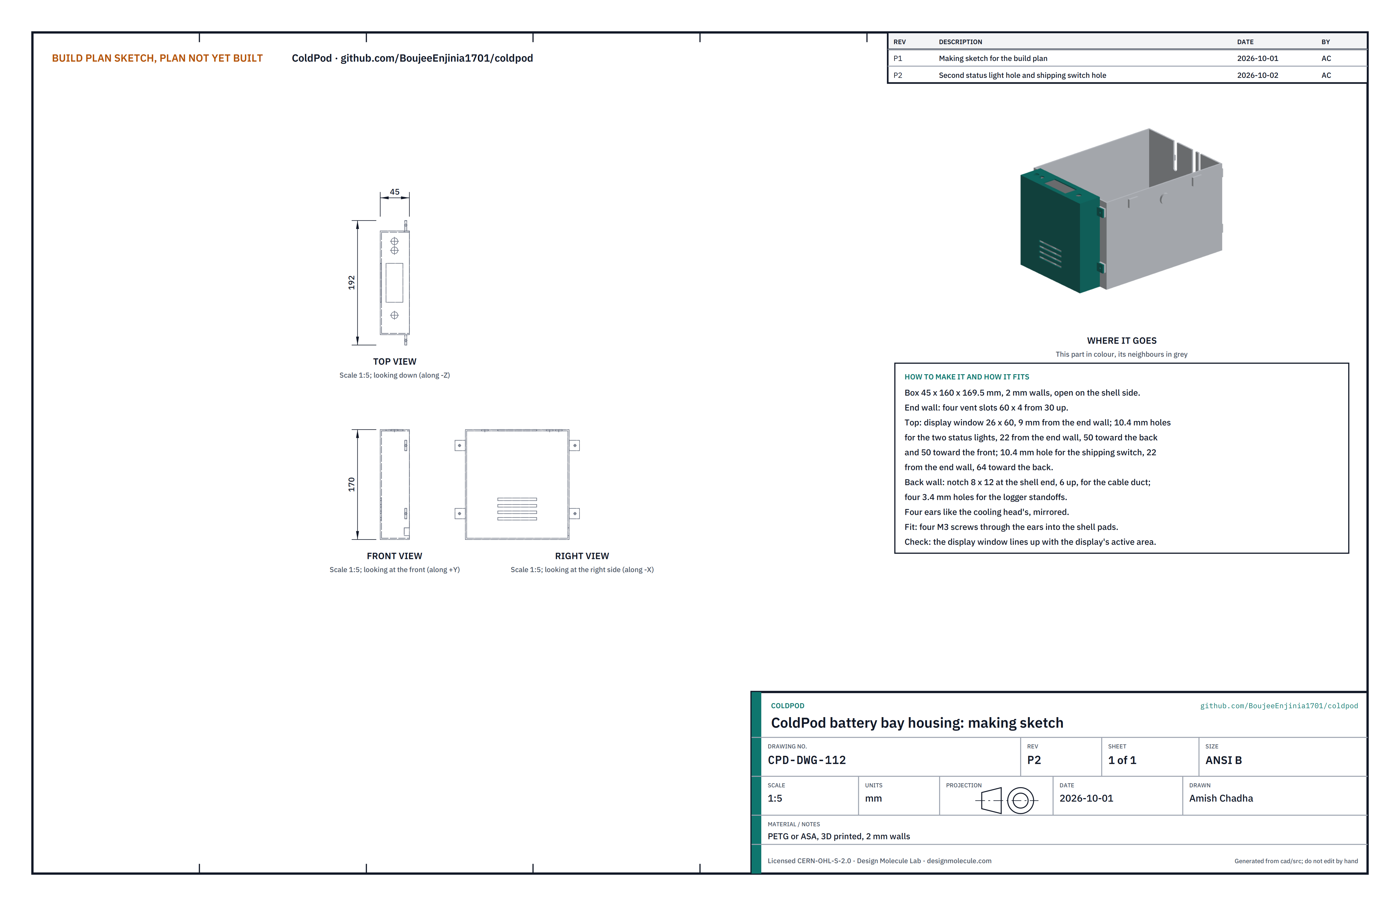
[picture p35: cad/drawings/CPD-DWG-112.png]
Figure 22. Making sketch of the battery bay housing


*Figure 22. Battery bay housing making sketch (CPD-DWG-112).*

**What it is and what it is made from.** The vented printed box for the battery, logger and display. PETG or ASA, 45 x 160 x 169.5 mm, 2 mm walls, open on the shell side.

**How to make it.** Print it open side down. Check four vent slots 60 x 4 from 30 up in the end wall; a display window 26 x 60 in the top, 9 from the end wall; two 10.4 mm holes for the status lights, 22 from the end wall, one 50 toward the back and one 50 toward the front; a 10.4 mm hole for the shipping switch, 22 from the end wall and 64 toward the back; the duct notch in the back wall; four 3.4 mm holes in the back wall for the logger standoffs; and four ears like the cooling head's.

**How it fits the parts next to it.** Four M3 screws through the ears into the shell's left-hand pads, as Figure 19. The logger stands on four M3 standoffs on the back wall, the display sits under its window, the two status lights are pushed into their holes from inside, and the shipping switch is fitted in its hole from inside and tightened with its nut.

**Check before moving on.** The display window lines up with the display's active area.

### 3.15 Cable duct cover

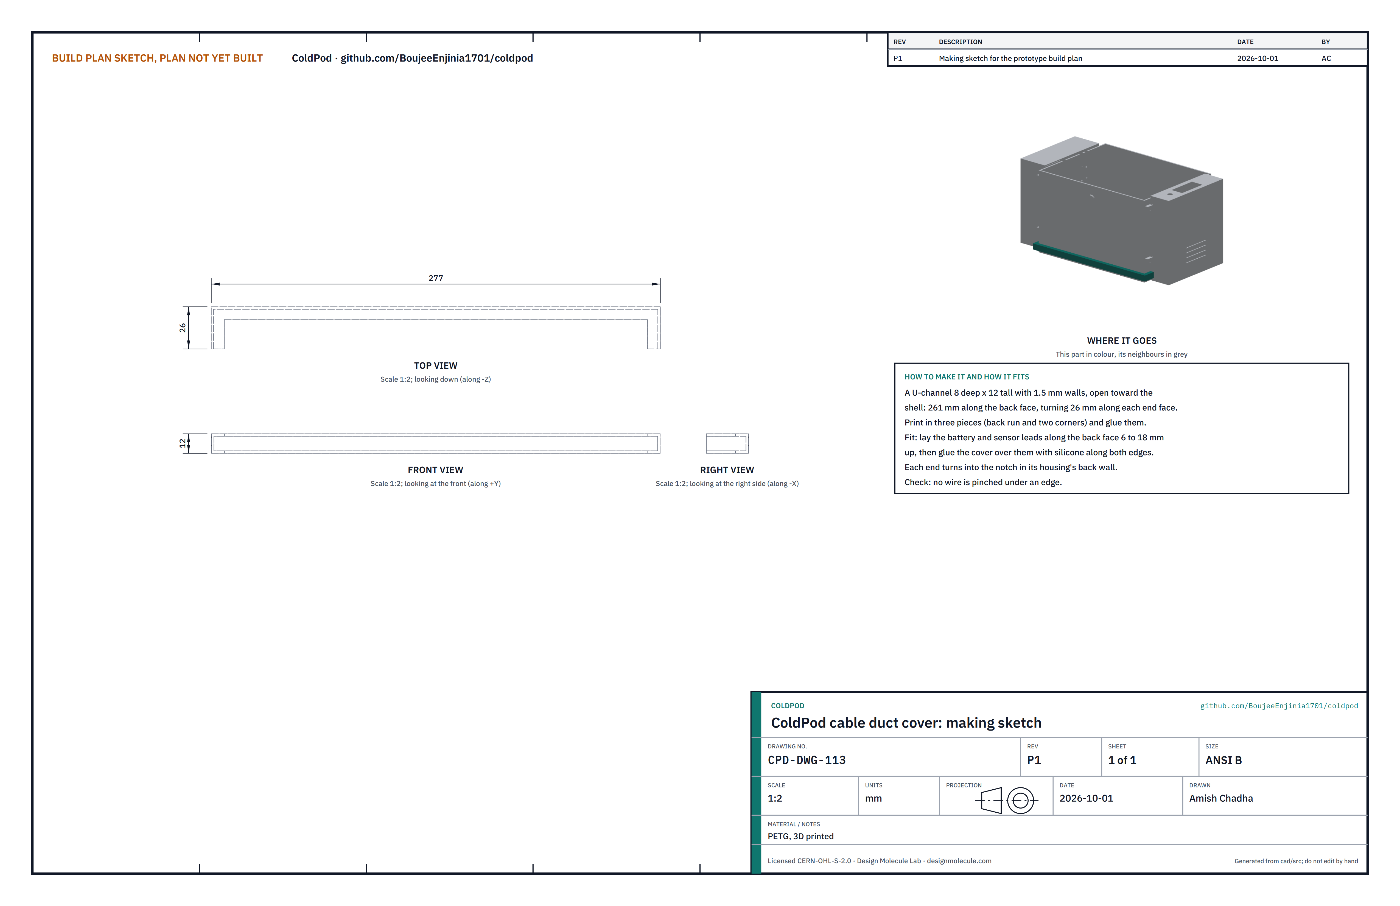
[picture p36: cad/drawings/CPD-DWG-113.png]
Figure 23. Making sketch of the cable duct cover


*Figure 23. Cable duct cover making sketch (CPD-DWG-113).*

**What it is and what it is made from.** A printed U-channel that carries the battery and sensor leads along the back of the shell from one housing to the other. PETG.

**How to make it.** Print a channel 8 deep and 12 tall with 1.5 mm walls, open on one side: a back run 261 long and a return 26 long at each end. Print it in three pieces and glue them.

**How it fits the parts next to it.**

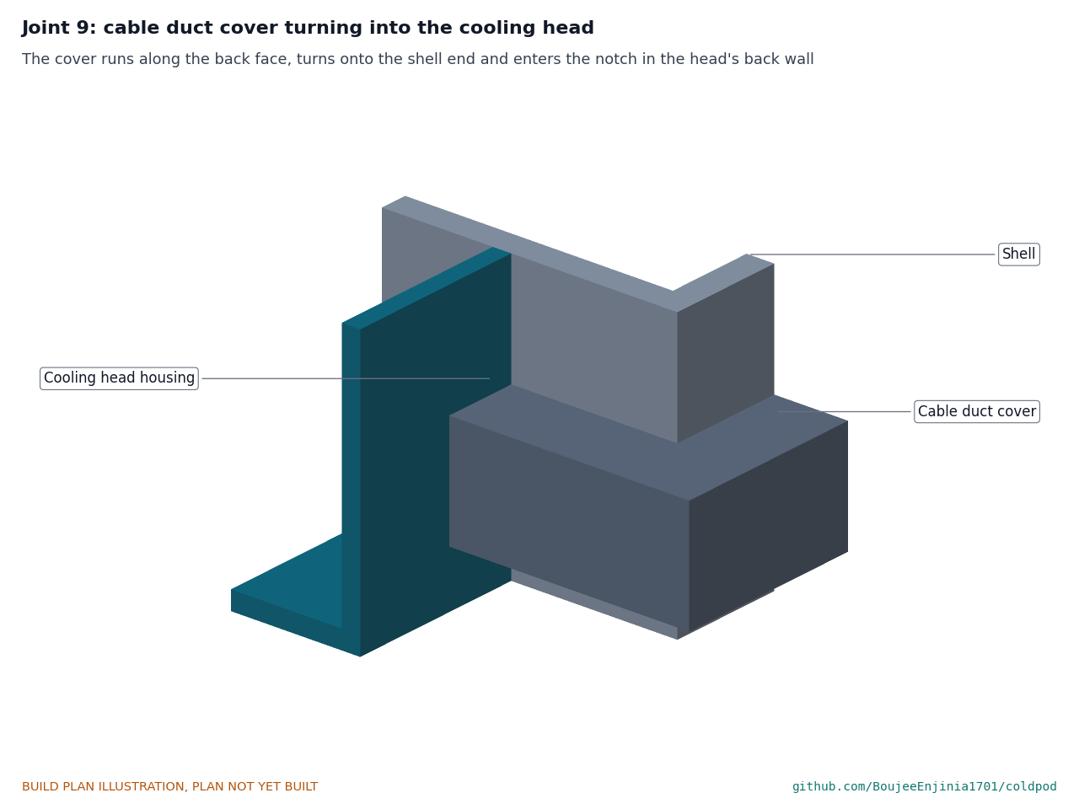
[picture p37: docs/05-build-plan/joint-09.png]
Figure 24. Joint 9: the duct cover turning into the cooling head


*Figure 24. The cover runs along the back face, 6 to 18 up, turns onto the shell end and enters the notch in the housing's back wall.*

The leads lie along the back face; the cover is glued over them with silicone along both edges.

**Check before moving on.** No wire is pinched under an edge.

### 3.16 Lid cold plate tray

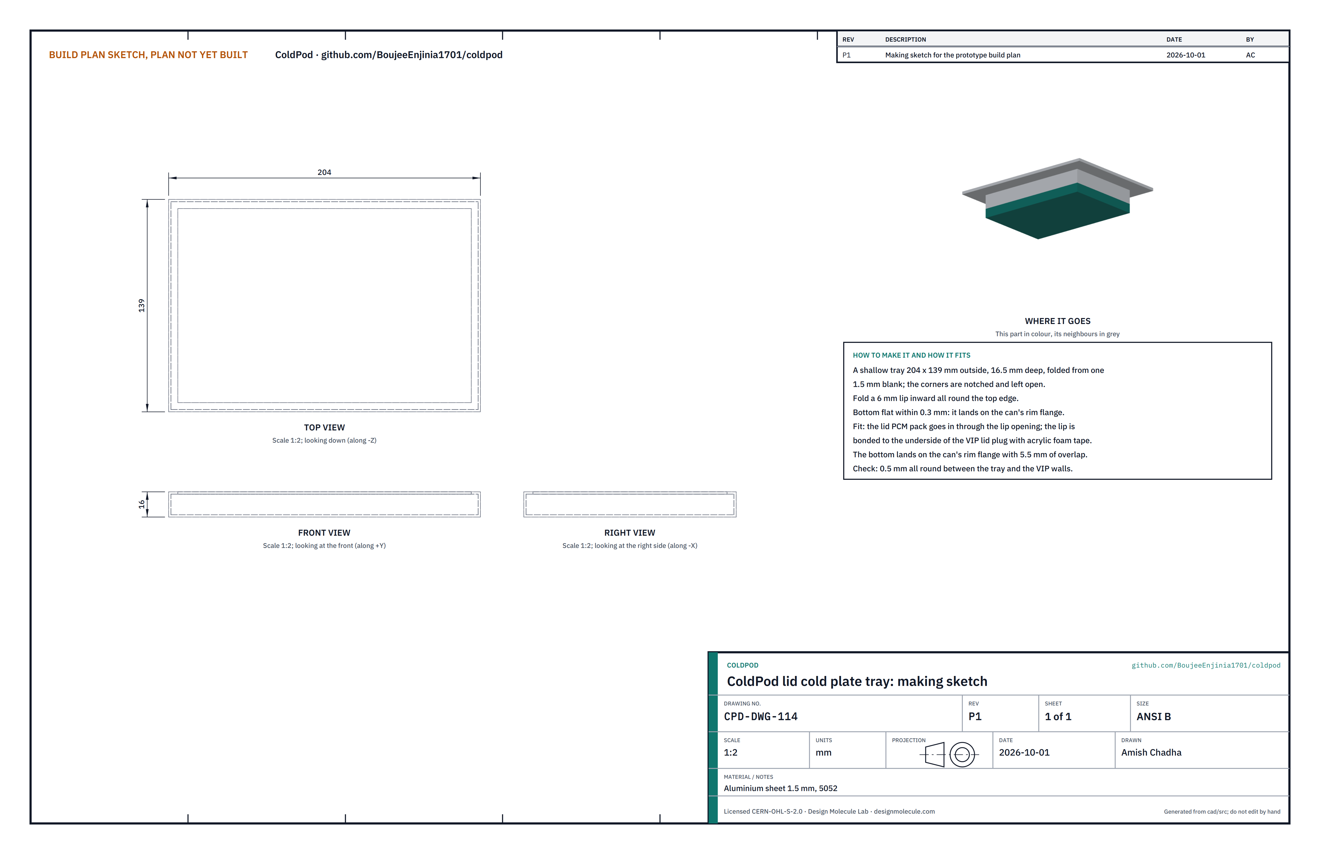
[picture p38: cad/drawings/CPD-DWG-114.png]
Figure 25. Making sketch of the lid cold plate tray


*Figure 25. Lid cold plate tray making sketch (CPD-DWG-114).*

**What it is and what it is made from.** A shallow aluminium tray that holds the lid PCM pack and, when the lid is closed, lands on the can's rim flange so the Peltier can freeze the lid pack too. Aluminium sheet 1.5 mm, 5052.

**How to make it.** Have a sheet metal shop fold a tray 204 x 139 outside and 16.5 deep from one blank, corners notched and left open, then fold a 6 mm lip inward all round the top edge. The bottom must be flat within 0.3 mm.

**How it fits the parts next to it.**

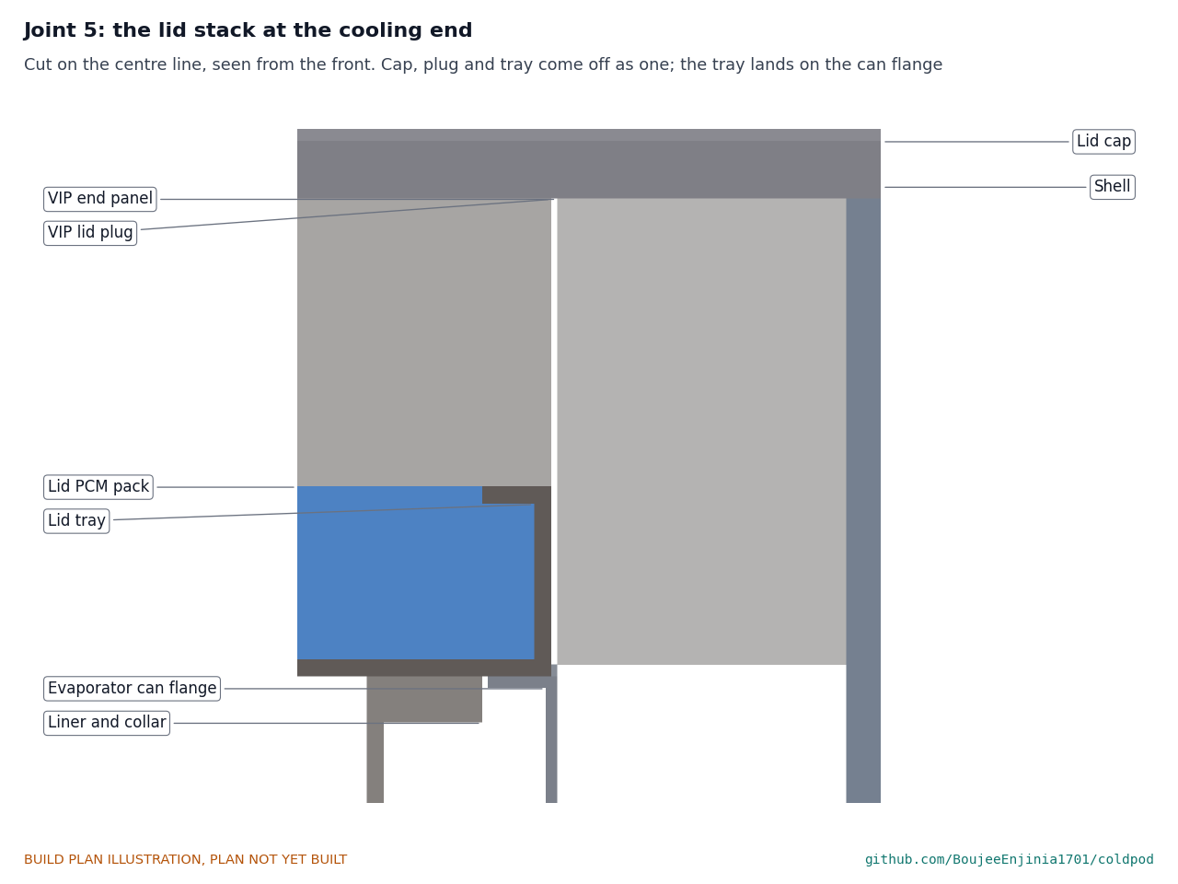
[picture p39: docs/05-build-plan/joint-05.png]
Figure 26. Joint 5: the lid stack


*Figure 26. Cut on the centre line at the right-hand end. Cap, VIP plug and tray come off as one; the tray lands on the can's rim flange.*

The lid PCM pack goes in through the lip opening. The lip is bonded to the underside of the VIP lid plug with acrylic foam tape. With the lid closed, the tray's bottom lands on the can's rim flange with 5.5 of overlap and 0.5 clear of the VIP walls all round.

**Check before moving on.** The tray drops into the opening without touching the VIP walls.

### 3.17 Lid cap

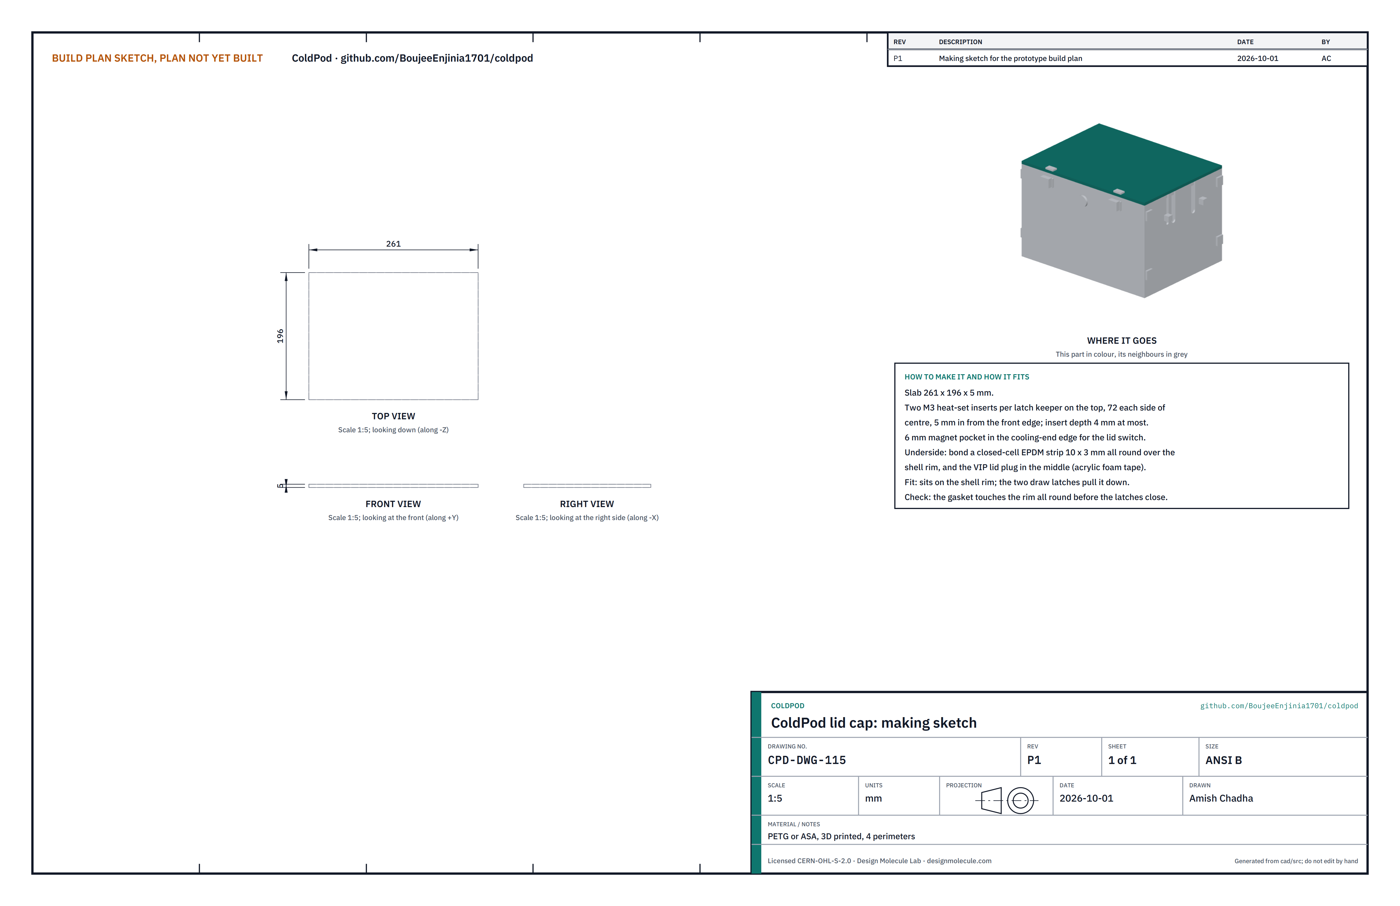
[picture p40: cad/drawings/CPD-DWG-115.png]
Figure 27. Making sketch of the lid cap


*Figure 27. Lid cap making sketch (CPD-DWG-115).*

**What it is and what it is made from.** The printed top of the case. PETG or ASA, 261 x 196 x 5 mm, four perimeters.

**How to make it.**

1. Print it flat.
2. Set two short M3 inserts for each latch keeper in the top, 72 each side of the centre and 5 in from the front edge, no deeper than 4 mm.
3. Glue a 6 mm magnet into a pocket in the right-hand edge for the lid switch.
4. Bond a closed-cell EPDM strip 10 x 3 all round the underside over the shell rim, and the VIP lid plug in the middle with acrylic foam tape.

**How it fits the parts next to it.** It sits on the shell rim on its gasket; the two draw latches pull it down.

**Check before moving on.** The gasket touches the rim all round before the latches close.

### 3.18 Bought components

Buy to specification, not brand. Line numbers are those of the bill of materials.

- **VIPs (line 4).** As section 3.2.
- **PCM pouches (line 5).** About 0.94 kg of organic PCM melting at 5 °C (RT 5 HC class) in sealed HDPE pouches: a floor pouch with a relief at each liner foot, two long side pouches, two left-end pouches and three narrow right-end pouches (one between the risers and one outside each), about 0.67 kg in all; and a lid pack about 0.27 kg that fits the tray.
- **Peltier module (line 8).** 40 x 40 mm, 127 couples, about 3 A maximum (TEC1-12703 class).
- **Heat sink and fan (line 9).** Finned aluminium sink 80 x 80 x 30 mm, 0.50 K/W or better with the fan; 70 mm 12 V fan; wire finger guard.
- **Battery (line 11).** Four 32700 lithium iron phosphate cells, 3.2 V, 6 Ah, from a maker that publishes a datasheet; four-cell battery management board with a charge temperature stop; 5 A fuse. The shipping switch (line 18) isolates the pack for field use and air travel; the carrier's lithium battery rules are checked before any such trip.
- **Power board modules (line 12), logger (line 13), sensors and cut-outs (line 14), display and lights (line 15), shipping switch (line 18).** As Table 2.
- **Handle and latches (lines 2 and 3).** Folding bail handle rated 10 kg or more with pivot eyes for M5 screws; padded 38 mm strap with two D-rings; two draw latches with keepers.
- **Construction parts (line 17).** 22 M3 and 2 M5 brass heat-set inserts, foam strip, 4 mm drain tube, acrylic foam tape.
- **Fixings and consumables (line 16).** M3 and M5 stainless screws, M3 standoffs, grommets, silicone sealant, two-part epoxy, thermally conductive epoxy, thermal paste, closed-cell foam tape, conformal coating, eight-core sensor cable, wire, ferrules and labels.

## 4. Putting it together

In each picture the parts already fitted are grey and the part being fitted is in colour, with an arrow showing the way it goes in.

### Step 1: VIP panels into the shell

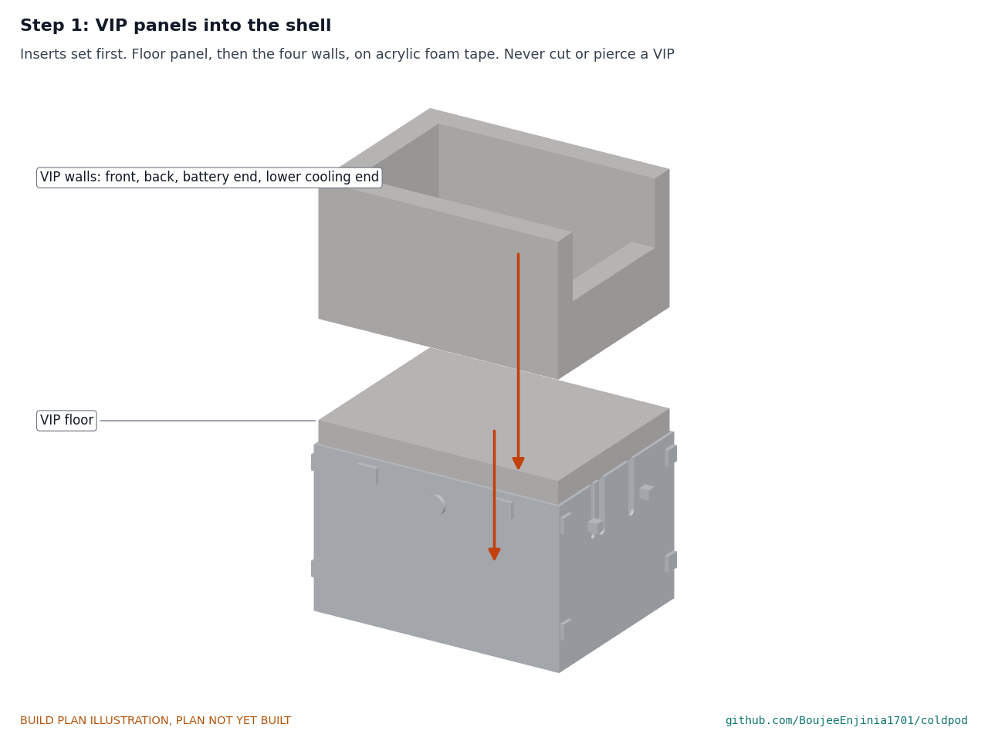
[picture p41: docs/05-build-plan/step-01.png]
Step 1


Inserts are already set (section 3.1). Floor panel first, then the front, back, left end and lower right end, each on strips of acrylic foam tape, edges butted tight. **Hold point:** safety stop S3.

### Step 2: loop into the can

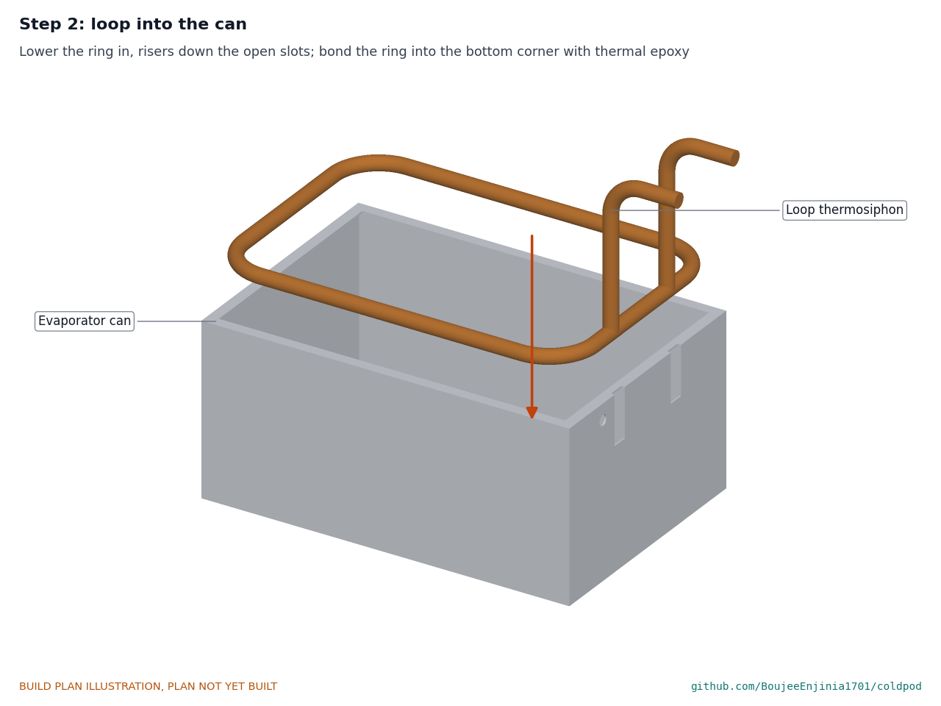
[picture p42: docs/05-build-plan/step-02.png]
Step 2


Lower the ring into the can with the risers dropping down the can's slots. Bond the ring into the bottom corner with thermally conductive epoxy and let it cure.

### Step 3: cold block onto the tails, then charge

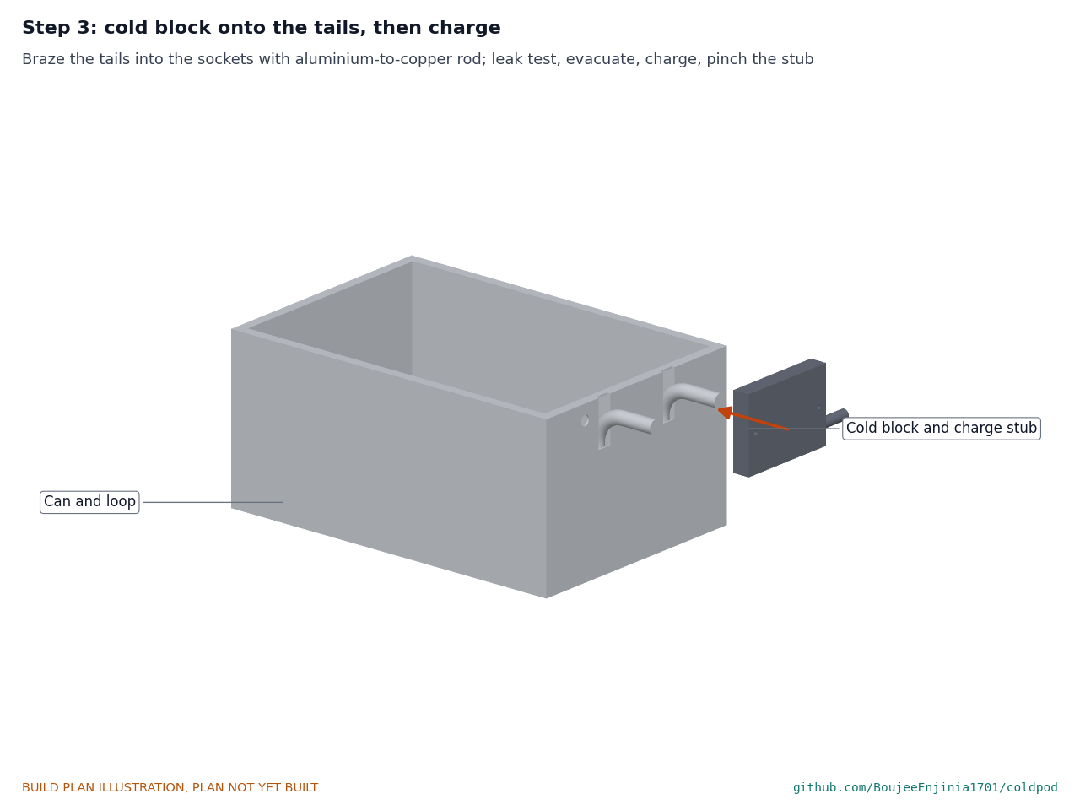
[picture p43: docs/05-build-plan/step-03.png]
Step 3


The technician brazes the tails and charge stub into the block, leak tests with dry nitrogen, evacuates, charges and pinches the stub. **Hold point:** safety stops S1 and S2; the loop holds its charge for 24 hours.

### Step 4: evaporator assembly into the VIP box

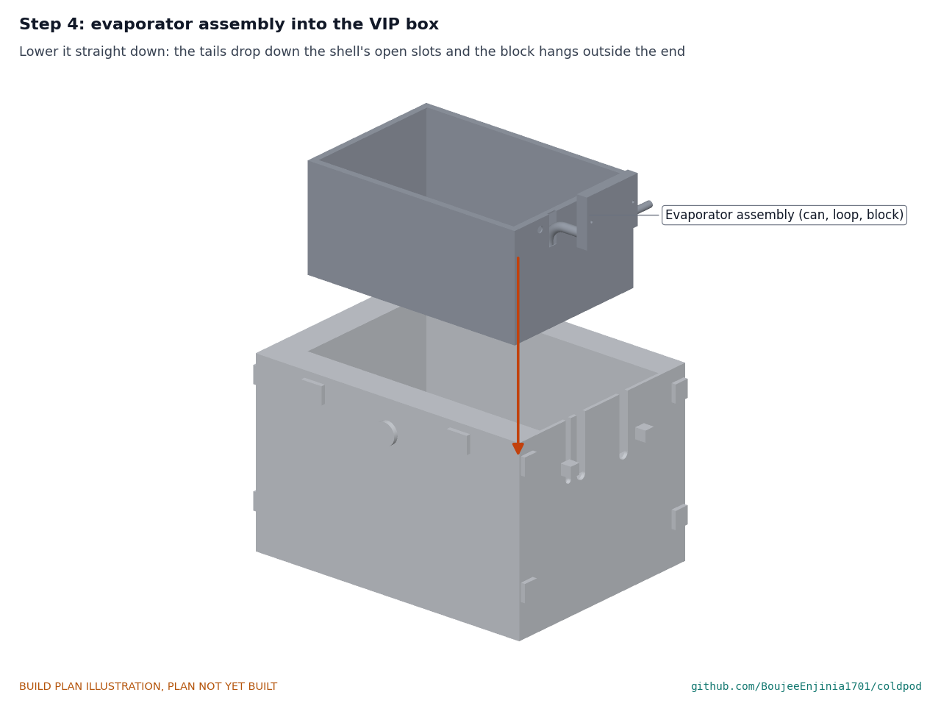
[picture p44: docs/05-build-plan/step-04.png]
Step 4


Lower the can, loop and block straight down into the VIP box. The tails drop down the shell's open slots and the block hangs outside the right-hand end.

### Step 5: foam strip, upper end panel and slot fillers

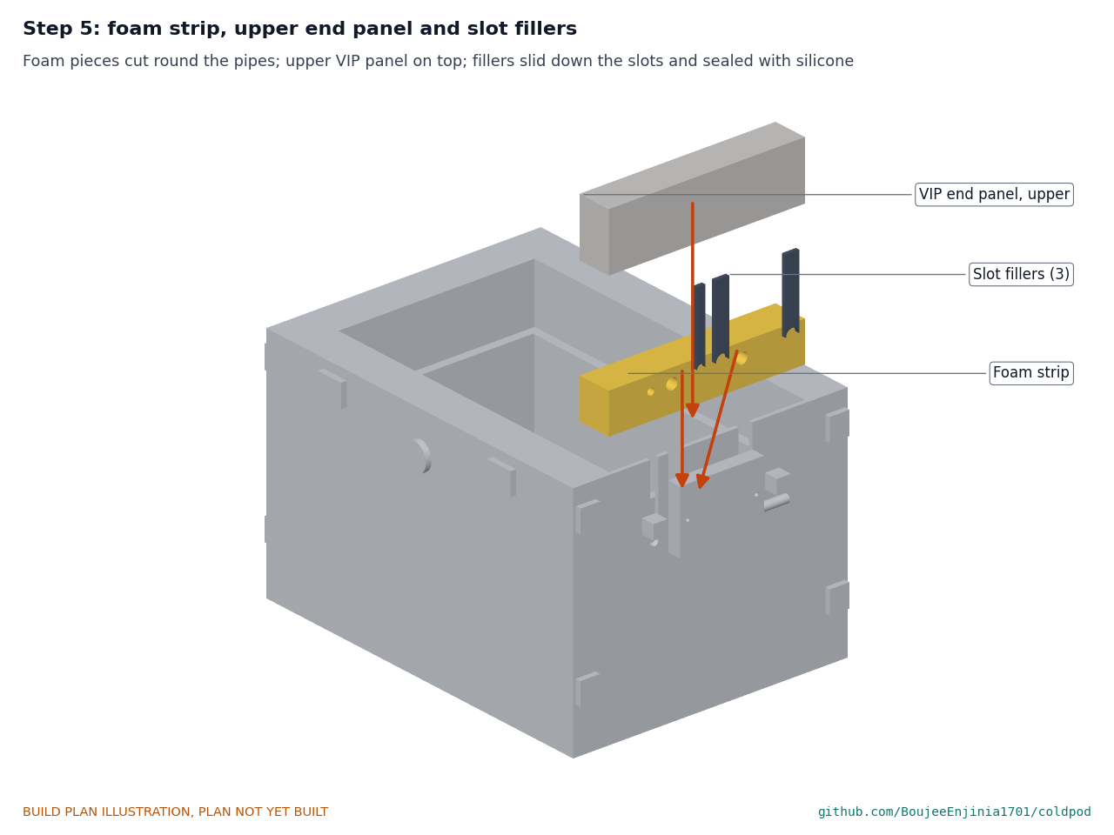
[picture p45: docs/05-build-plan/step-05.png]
Step 5


Cut the foam strip into an upper and a lower piece round the pipes and fit it; feed the sensor cable through its slot as you do. Lay the upper right-end VIP on the foam. Slide the three fillers down their slots onto the pipes and cable and seal them with silicone.

### Step 6: PCM pouches into the can

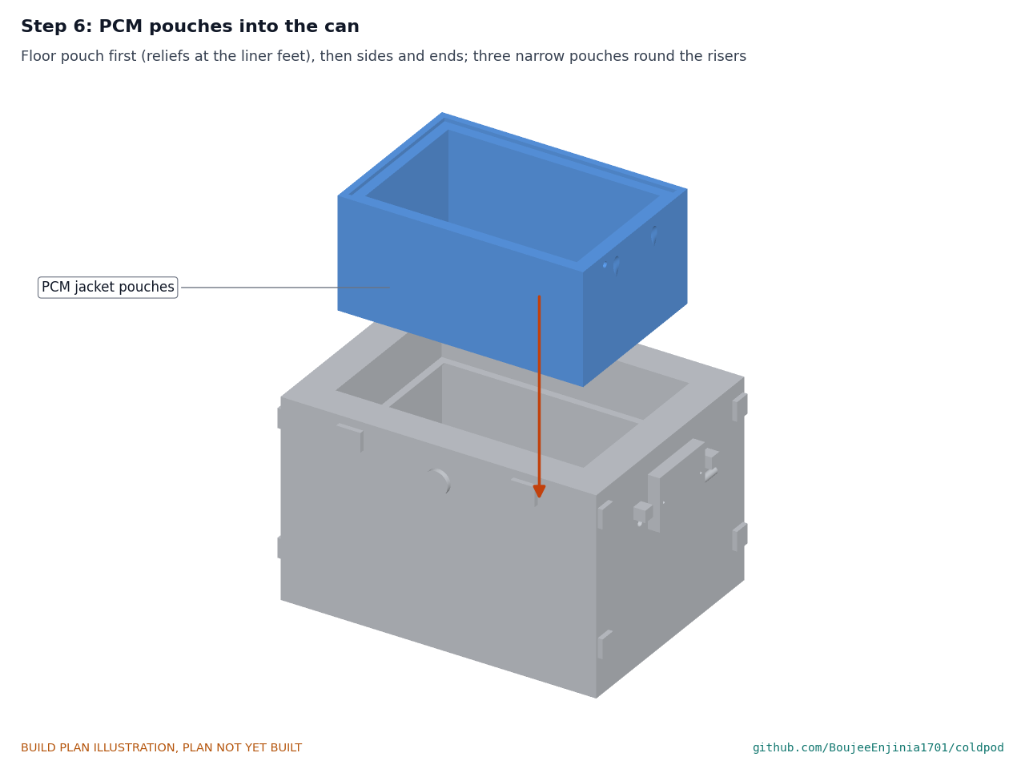
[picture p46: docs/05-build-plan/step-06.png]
Step 6


Floor pouch first, its reliefs at the four feet positions; then the side, left-end and the three narrow right-end pouches round the risers. **Hold point:** safety stop S8; no brazing or hot work from here on.

### Step 7: liner sub-assembly

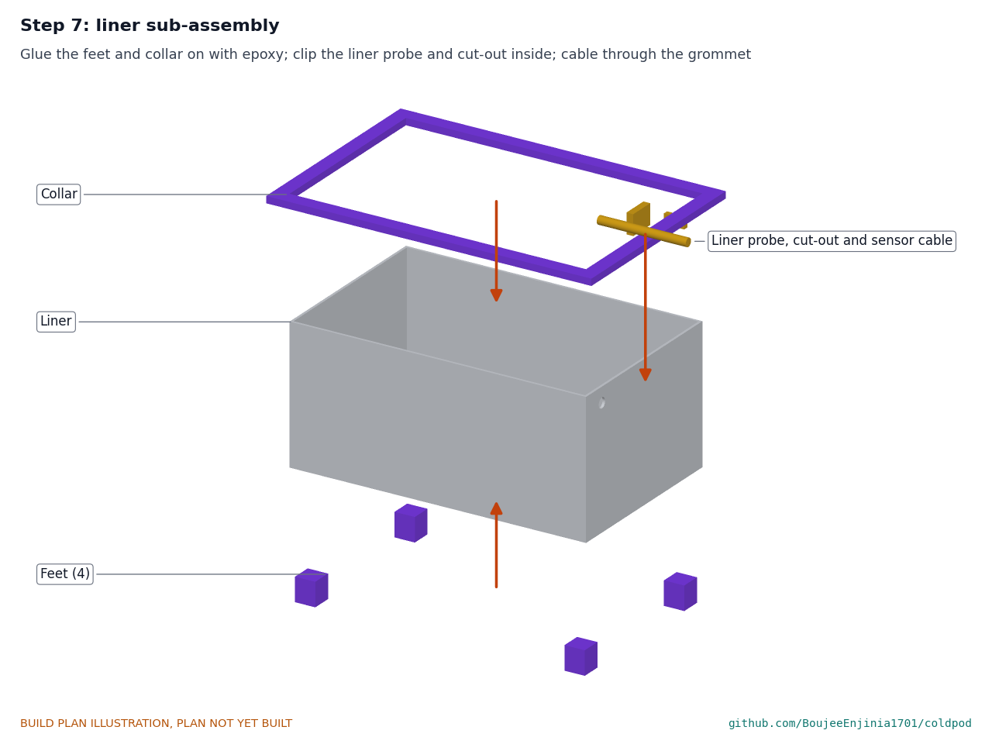
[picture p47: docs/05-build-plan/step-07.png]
Step 7


On the bench: feet and collar glued on, liner probe and cut-out clipped inside, sensor cable through the liner grommet (section 3.7).

### Step 8: liner into the can

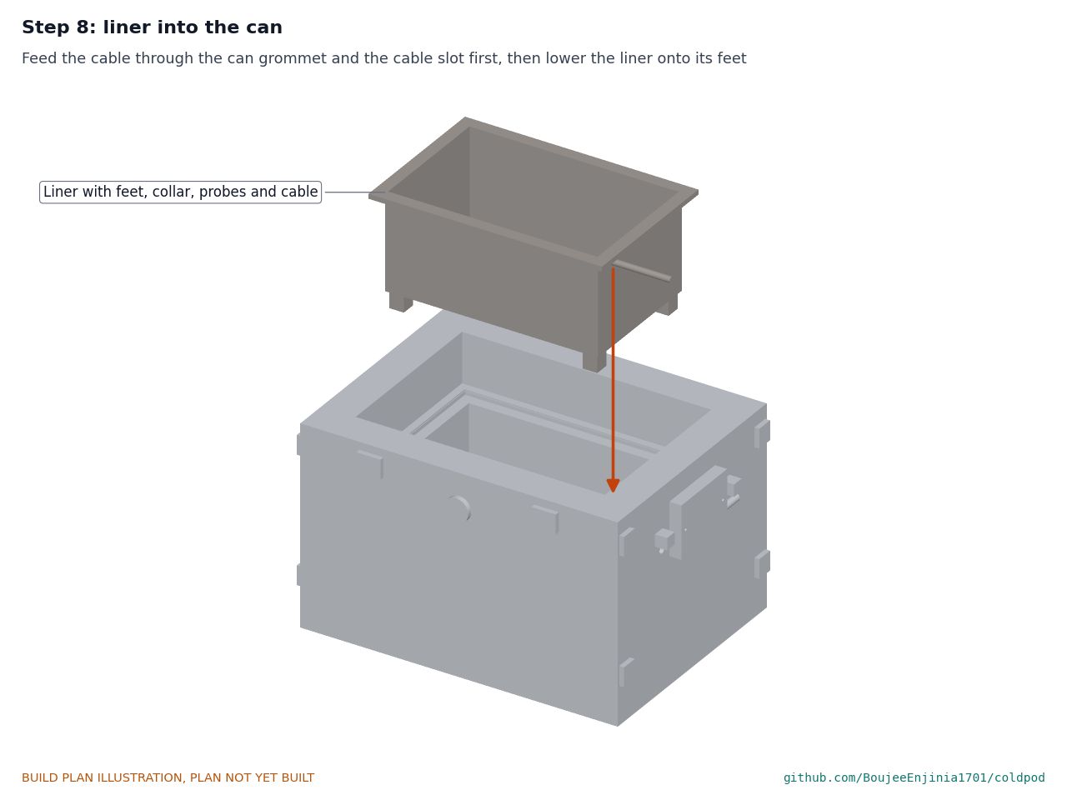
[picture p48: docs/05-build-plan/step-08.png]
Step 8


Feed the sensor cable through the can's grommet first, then lower the liner onto its feet. The collar centres it inside the rim flange.

### Step 9: rack and payload probe into the liner

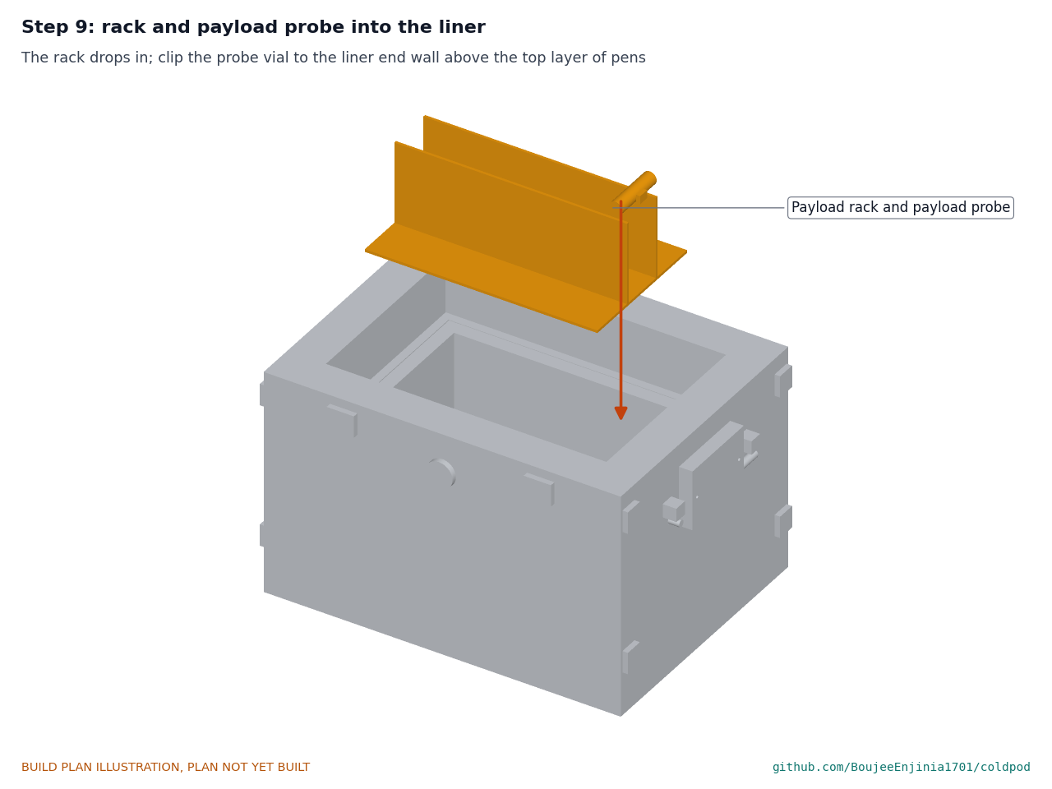
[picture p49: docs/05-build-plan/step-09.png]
Step 9


Drop the rack in and clip the probe vial to the liner's right-hand wall above where the top layer of pens will lie.

### Step 10: block frame and drip tray onto the towers

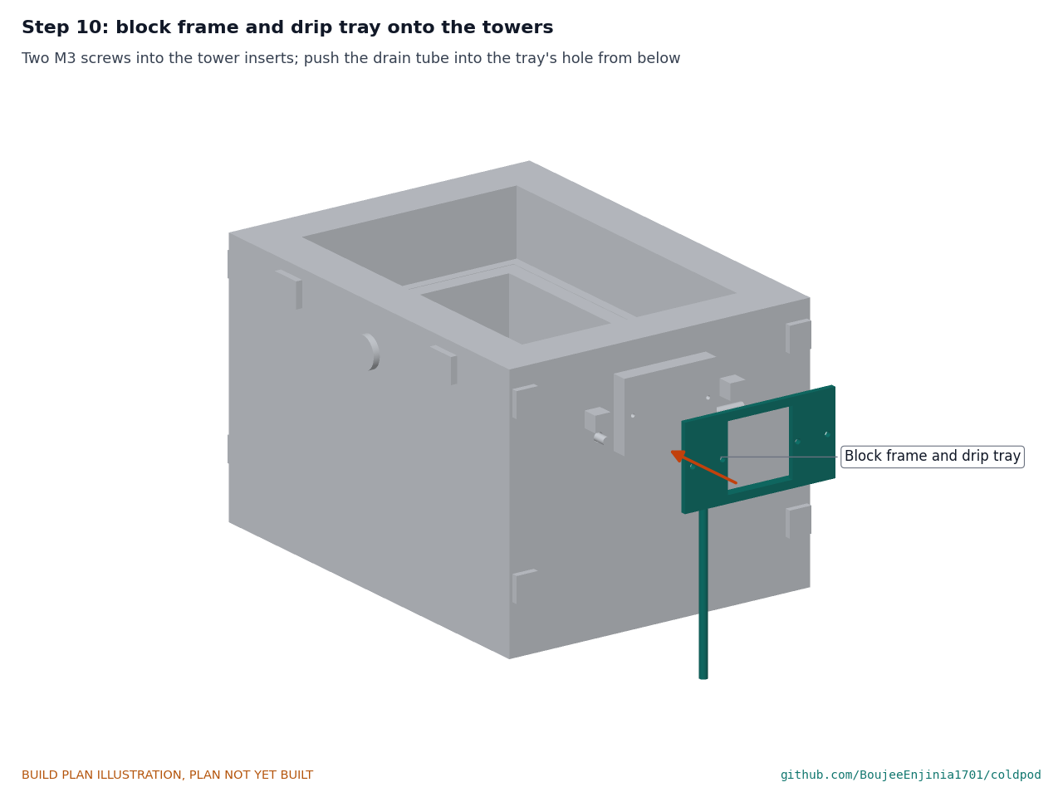
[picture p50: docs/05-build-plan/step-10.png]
Step 10


Two M3 screws through the frame into the tower inserts, snug. Push the drain tube up into the tray's hole from below.

### Step 11: Peltier module and heat sink onto the block

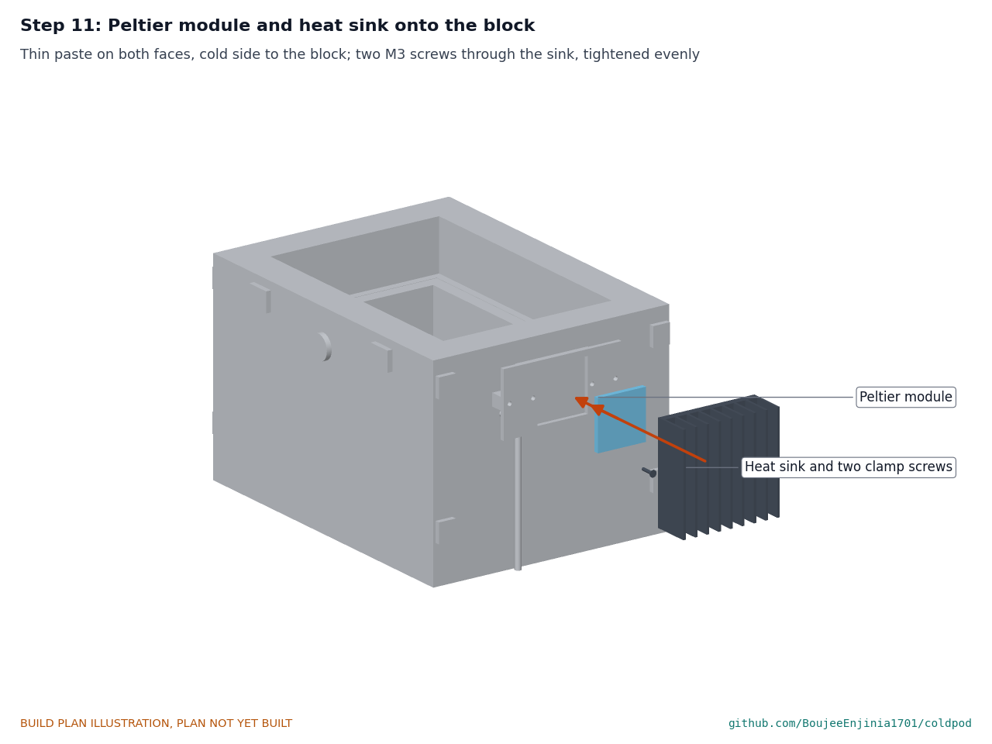
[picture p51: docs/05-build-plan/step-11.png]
Step 11


A thin even layer of thermal paste on both module faces, cold side to the block (check the maker's marking). Heat sink on the module, two M3 screws through the sink into the block, tightened a little at a time in turn. Wrap the block's exposed edges and the tails in closed-cell foam tape.

### Step 12: fan and guard onto the sink

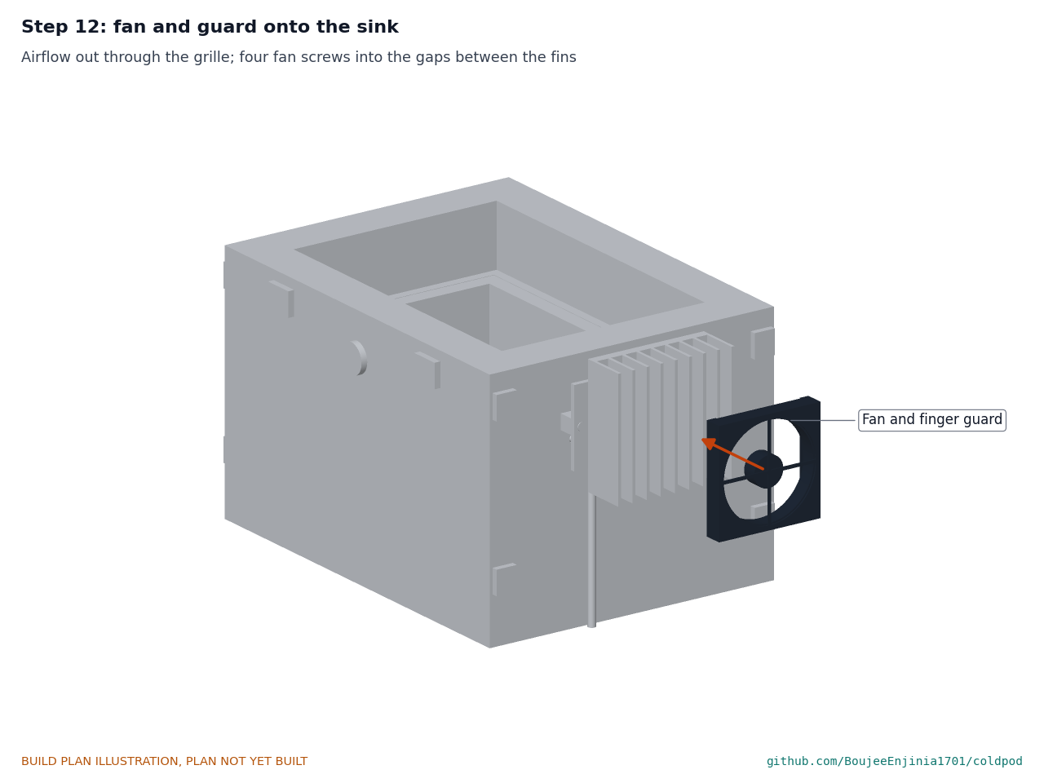
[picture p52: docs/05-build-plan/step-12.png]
Step 12


Fan blowing out through the grille, finger guard on its outer face, four fan screws into the gaps between the fins.

### Step 13: build the cooling head

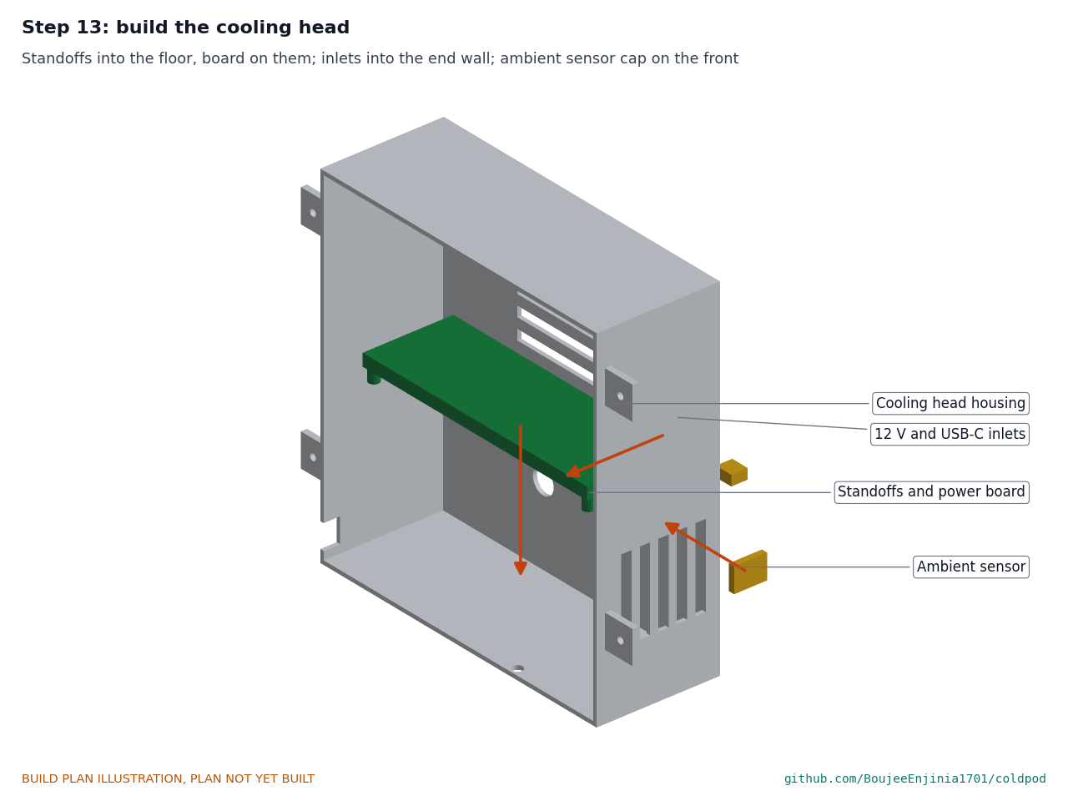
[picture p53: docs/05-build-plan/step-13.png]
Step 13


On the bench: standoffs into the floor, power board on them, inlets into the end wall, ambient sensor cap on the front, reed switch inside the top. Wire as section 3.12. **Hold point:** the wiring checks of section 3.12 pass.

### Step 14: cooling head onto the shell

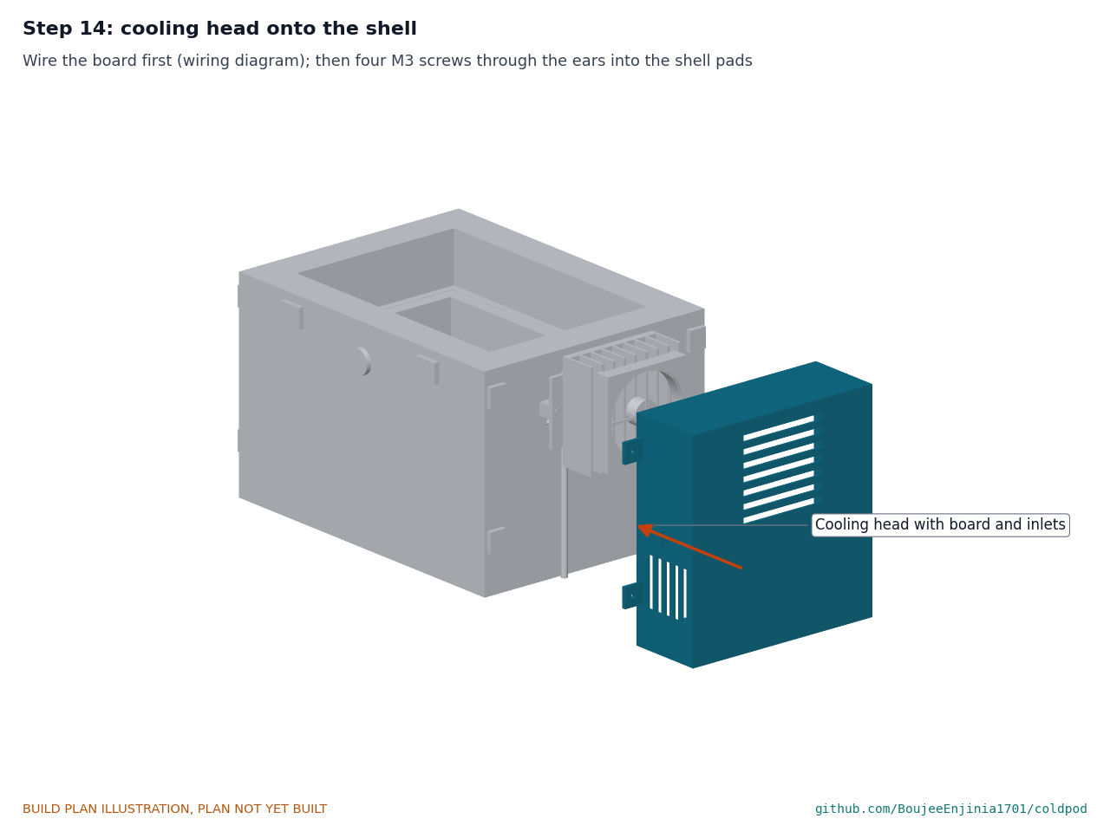
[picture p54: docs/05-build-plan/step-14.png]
Step 14


Connect the module, fan, cut-out and drain; slide the housing over the stack; four M3 screws through the ears into the shell pads.

### Step 15: build the battery bay

Step 15

On the bench: cradle screwed to the floor, cells in, battery management board on top, strap; logger on its standoffs on the back wall; display under its window, the two status lights in their holes and the shipping switch in its hole, switched off. **Hold point:** safety stop S4; fuse out.

### Step 16: battery bay onto the shell

Step 16

Fuse still out. Connect the duct leads, then four M3 screws through the ears into the left-hand pads.

### Step 17: cable duct cover onto the back face

Step 17

Seen from the back. Lay the battery, 3.3 V and sensor leads along the back face 6 to 18 up and glue the cover over them.

### Step 18: handle and latches

Step 18

Handle on two M5 pivot screws, the strap's D-rings under the screw heads; latches on two M3 screws each, keepers on the lid cap.

### Step 19: build the lid

Step 19

Seen from below. VIP plug onto the cap with acrylic foam tape; lid pack into the tray; the tray's lip onto the plug with foam tape.

### Step 20: lid on

Step 20

Fold the handle down to one side, lower the lid straight down and close both latches. **Hold point:** safety stops S5 to S7 before any power.

## 5. First checks

These are the checks a TRL 4 test report would record; this plan only lists them. Requirement numbers are those of CPD-REQ-001.

*Table 3. First checks.*

| Check | Requirement | How | Pass when |
| --- | --- | --- | --- |
| Payload fits | R3 | Load 24 rods 16 mm across and 160 mm long, and one 172 mm long | All fit; the lid closes; the probe vial clears the top layer |
| Lid seal and tray landing | R1, R16 | Close the lid on a strip of thin paper at several points round the gasket, then on a strip on the can flange | The paper is gripped at every point on both |
| Loop sealed | R7 | The technician's 24 hour charge check | No change in the gauge reading |
| Cut-outs | R2 | Chill each cut-out (ice water for the liner one, a freezer for the block one) with the module supply on a bench supply at low current | The supply opens at each cut-out without any firmware running |
| First cooling on a bench supply | R7 | 12 V, current limit 3 A, box empty; watch the block probe and the sink | The block cools within a minute; the fan runs; the sink stays below 60 °C |
| Input range | R7 | Bench supply at 10 V and at 15 V; then a USB-C PD charger | The driver runs the module at its set point on all three |
| Charge stops | R14 | Battery charging from the bench supply; substitute the board's temperature sensor with resistors for -1 °C and 46 °C | No charge current in either case |
| Logger and probes | R9 | Read all four probes in a room and in an ice-water bath | Each within ±0.5 °C of a reference thermometer |
| Alarms | R10 | Open the lid; unplug a probe; warm the payload probe by hand past 8 °C | Lid-open, sensor-fault and out-of-range alarms sound and show |
| Drain | R16 | Pour 20 ml of water into the drip tray | It leaves through the head floor; the power board stays dry |
| Size and mass | R12, R13 | Measure over the handle; weigh empty | Within 400 x 250 x 250 mm; mass recorded (5.74 kg estimated) |
| Battery removal | R14 | Remove the battery bay and unplug the duct leads | The pack comes out with a screwdriver |

## 6. Safety stops

Stop at each point. Carry on only when everything listed is true.

- **S1. Before any brazing.** The can, loop and block are on a steel bench with no plastic, VIP, PCM or paper within 1 m. Work in a ventilated space with a fire extinguisher at hand. Brazing is done by a technician trained in it, with eye protection and a nitrogen purge.
- **S2. Before the loop is charged.** The technician is qualified to handle refrigerants where you live. The working fluid is R-134a (non-flammable, safety class A1); the technician sets the charge from the loop volume. The loop has passed a dry nitrogen leak test at the technician's test pressure. Eye protection and gloves; never heat a charged loop.
- **S3. Before the VIPs come out of their packaging.** No knives, drills or sharp tools on the bench. Handle panels by their faces, never by a corner.
- **S4. Before the cells come into the workshop.** Each cell reads about 2.8 to 3.4 V, with no swelling, dents or leaks and a datasheet from its maker. The fuse is out. A charging spot is ready on a non-combustible surface with a fire extinguisher for electrical fires.
- **S5. Before first power to the Peltier module.** The heat sink is clamped and the fan connected: a module run without its heat sink overheats in seconds. Both cut-outs are in series in the module supply and pass their check. The bench supply current limit is 3 A or less.
- **S6. Before the battery fuse goes in.** Polarity checked with a meter at the battery board, not by wire colour; with the fuse out, no rail reads short to ground; the charger stops at 14.4 V on a bench check.
- **S7. First charge.** Attended the whole time, lid open, case on the charging spot; cell temperature checked every 15 minutes. Stop if a cell passes 45 °C or 3.65 V.
- **S8. Once the PCM is in.** The paraffin is combustible: no brazing, soldering or hot work on the case from here on, and any leaking pouch is replaced at once.
- **S9. Before the case leaves the workshop.** It is labelled "Research prototype, not a medical device"; it carries no real vaccines or medicines.

## 7. Tools, skills and workspace

**Tools.** 3D printer with a bed of at least 300 x 300 mm and 180 mm of height, enclosed for ASA; soldering iron with heat-set insert tips for M3 and M5; lever tube bender for 8 mm tube and a tube cutter; drill press, drills 2.5 to 12 mm, M3 tap; files and deburring tool; steel rule, calipers, square and a surface plate or flat glass for checking flatness; utility knife for foam only; ferrule crimper and wire strippers; soldering iron for wiring; multimeter; bench power supply 0 to 20 V, 0 to 5 A with a current limit; USB-C PD charger of 45 W or more; two reference thermometers; scale to 10 kg. The sheet metal parts (can, liner, tray) and the brazing, leak testing and charging need a sheet metal shop and a refrigeration technician with their own tools.

**Skills.** Printing large parts in PETG or ASA; setting threaded inserts; simple tube bending; soldering and crimping; safe use of a bench supply and care with lithium cells. All circuits are 20 V DC or less; no mains wiring is part of this build. Brazing, refrigerant handling and charging are trades: use a qualified technician.

**Workspace.** A bench about 1.5 x 0.75 m kept clean and free of sharp tools for the VIP work; a separate steel bench or outside space for brazing; a ventilated place for the printer; the charging spot of S4.

**Personal protective equipment.** Safety glasses for drilling, brazing and charging; gloves for sheet metal edges and refrigerant work; no gloves near a turning drill.

## 8. Where the numbers come from

- Model and constructability checks: `cad/src/model.py` (`python cad/src/model.py --check`, 63 checks); STEP and STL exports in `cad/step/` and `cad/stl/`.
- Pictures: `cad/src/build_plan_media.py`, using `.kit/build_views.py`; written to `docs/05-build-plan/` and `cad/drawings/CPD-DWG-101` to `CPD-DWG-115`.
- General arrangement: `cad/drawings/CPD-DWG-001.pdf`, Rev P4.
- Calculations: `docs/04-calcs/01-sizing.md` (CPD-CAL-001 v0.4) and `docs/04-calcs/sizing.py`; size [A6], heat leak [B9], PCM [C2], hold times [D2, F2], refreeze [G4], thermosiphon [H4, H5], mass [K2], cost [L2].
- Bill of materials: `bom/bom.csv`.
- Decisions: `docs/decisions/0003-design-for-construction.md` (CPD-DDR-003), with CPD-DDR-001 and CPD-DDR-002.
- Requirements: `docs/03-requirements.md` (CPD-REQ-001 v0.6).

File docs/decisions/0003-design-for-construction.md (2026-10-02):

---
doc_id: CPD-DDR-003
title: ColdPod design for construction
project: ColdPod
doc_type: Design decision record
version: "0.3"
status: Draft
date: '2026-10-02'
author: Amish Chadha
license: CERN-OHL-S-2.0
revisions:
- version: "0.1"
  date: '2026-10-01'
  author: Amish Chadha
  change: Changes that make the concept physically buildable, with the reason for each; made under Amish's 2026-09-30 instruction to make the design physically buildable; open for his review
- version: "0.2"
  date: '2026-10-01'
  author: Amish Chadha
  change: Budget treated as a value-engineering target
- version: "0.3"
  date: '2026-10-02'
  author: Amish Chadha
  change: "Accepted by Amish (2026-10-02), with A1 to A4 as recommended (A4: R-134a); status kept Draft"
---

# 0003: Design for construction

- **Date:** 2026-10-01
- **Status:** accepted. Amish, 2026-10-02: "i approve your recommendations for all 555 open decisions." This covers every change in Table 1 and its knock-on changes, and the recommendations for A1 to A4 in Table 3, which are now decided and recorded in the design decisions register (CPD-DEC-001). Nothing in this record changes what ColdPod does or its pitch; A3 and A4 add safety rules (below).

## Context

On 2026-09-30 Amish asked for a build plan that shows how each component is made and how it fits the next, with pictures, and wrote: "If you are realising that the design cannot be built as per concept - fix the design assumptions to match and be physically feasible as you draw the illustrations." The TRL 3 model (CPD-DDR-002) showed what ColdPod does and sized it, but many of its parts were massing shapes: they touched only by coincidence, had no fixing, or could not be made or put together as drawn. Checking the model with build123d (every pair of parts tested for overlap and gap) found one overlap, the payload probe inside the pens (2.35 cm³), and showed that the loop, the cold block stack, the end housings, the liner, the lid cold plate, the handle, the electronics and the cables had no fixing or route. A closer look at the way the parts go together found the rest.

The governing constraint is the vacuum-insulated panels: a VIP behind every wall of the shell means no screw, rivet or drill may ever pass through a shell wall. Every outside fixing therefore lands on a printed pad or tower on the shell, with a heat-set insert that stops short of the panel.

The changes keep what ColdPod does: the same payload space and pen layout, the same layers (liner, 5 °C PCM jacket and lid pack, evaporator can, 25 mm VIPs, printed shell), the same loop thermosiphon, Peltier module, heat sink, battery, electronics, cut-outs and alarms, and the same overall length and height. Every change is in `cad/src/model.py`, which now builds 48 separate components (49 with the payload) and runs 63 constructability checks (`python cad/src/model.py --check`): parts that must touch do touch, parts that must clear do clear, and no other pair of the 1,176 overlaps. All 63 pass.

## Decision

*Table 1. Changes made to the model, the BOM and the calculations.*

| # | Problem in the concept | Change made | Why this way |
| --- | --- | --- | --- |
| P1 | The buffered payload probe (14 x 36 mm, standing in the corner of the liner) overlapped the pens of the first column by 2.35 cm³. | A 10 x 40 mm buffered vial lying across the top layer of pens at the cooling end, held by a printed clip on the liner's end wall, 1.8 mm above the pens and 1.5 mm below the lid tray. | Keeps 24 pens of up to 172 mm. The space above the top layer (12.5 mm) was empty. Where the probe should sit to read the warmest pen stays an open question in CPD-PRC-001. |
| P2 | The evaporator loop floated 5 mm inside the PCM jacket, touching nothing, with sharp corners. Sealed pouches cannot be "formed around the tubes". | The ring lies in the bottom inside corner of the can, touching floor and wall, bonded with thermally conductive epoxy; corners bent to 25 mm radius. | The can is the evaporator; a tube bonded to it feeds the whole can. The condenser now sits 81 mm above the loop (76 mm), so the tilt limit with the cooling head down rises from 18° to 19°. |
| P3 | Each riser turned 90° to horizontal inside the 14 mm gap between liner and can, which no tube bender can do, and left through round holes in the can and the shell, so a one-piece loop could never be put in. | Risers bend at 17.5 mm radius (a lever bender for 8 mm tube), with most of the bend inside the foam strip. The can has two riser slots and the shell three slots (two pipes, one cable) open at the rim; three printed slot fillers close the shell slots after assembly. The foam strip grows from 20 to 28 mm tall (18 mm below to 10 mm above the pipes) so the bend clears the lower VIP panel by 1 mm or more. | The whole loop, block and charge stub can then be made, leak tested and charged on the bench by a refrigeration technician, and lowered into the case as one sealed unit. |
| P4 | The cold block had no condensing passage and no joint to the copper tubes. | Two 8.1 mm tube sockets in its back face, a 6 mm condensing passage drilled through both, and a 6 mm copper charge stub in the passage mouth; tubes and stub joined with aluminium-to-copper brazing rod; the stub is pinched shut after charging. | A sealed refrigerant circuit with the aluminium block as condenser, as sized in CPD-CAL-001 section H. |
| P5 | The Peltier module, heat sink and fan hung on the two copper tubes. | A printed block frame (3.5 mm, thinner than the 4 mm module) holds the block against the shell end and is screwed to two printed towers on the shell. Two M3 screws through the heat sink base into the block clamp the module. The fan and a finger guard screw to the sink. | The stack is held by the shell, not the tubes. The frame never touches the hot sink (0.5 mm gap), so it is not a heat path, and the clamp force goes through the module. |
| P6 | The end housings had no fixing, and the shell can take no screw through its walls. | Four printed pads with M3 heat-set inserts on each end face of the shell, and four ears on each housing; one M3 screw per ear. | Respects the VIP rule; the housings come off for service with four screws. |
| P7 | The handle pivots and the two draw latches had no fixing. | Printed pads on the shell: two with M5 inserts for the handle pivots, two with M3 inserts for the latches; keepers on the lid cap with short inserts. The strap clips to D-rings under the pivot screws. The handle arms move out 4 mm each side. | Same VIP rule. Overall width rises from 212 to 220 mm, inside R13's 250 mm. Latch and strap positions follow the recommendations already made for the appearance model (`docs/REVIEW.md`, 2026-09-26, items 4 and 7). |
| P8 | The liner rested on the PCM pouch with no location; the lid cold plate was a flat sheet that "seats on the can rim" on a 1 mm edge, with no fixing to the lid. | The can gets a 5 mm inward rim flange. The liner stands on four printed feet (12 x 12 x 14 mm) on the can floor and is centred by a printed collar inside the flange. The lid cold plate becomes a folded tray (204 x 139 x 16.5 mm, 6 mm inward lip) that holds the lid pack, bonded to the lid VIP plug, which is bonded to the cap; the tray lands on the flange with 5.5 mm of overlap. | Plastic feet and collar keep the liner off the can (design choice 3). The flange gives the tray a real landing for the 0.5 K/W seat that CPD-CAL-001 assumes. Cap, plug, tray and pack lift off as one. |
| P9 | The VIPs were one solid box. | Seven panels bought to size (floor, front, back, battery end, cooling end lower and upper, lid plug), butt jointed on acrylic foam tape, with the foam strip cut round the pipes and cable; the lid plug and tray 0.5 mm under the opening. | VIPs are ordered to size and can never be cut; the list in BOM line 4 is the order. |
| P10 | The power board, logger, cells and display touched nothing. | Power board on four M3 standoffs on the head floor; cells in a printed cradle with the BMS on top and a strap; logger on four standoffs on the bay's back wall; display under a window in the bay top; alarm light in a hole. | Standard fixings for bought modules. |
| P11 | Condensate from the cold block and pipes would drip onto the power board below them. | A drip tray printed on the block frame, draining through a 4 mm tube and a hole in the head floor, clear of the board. | The concept says the cooling head drains outward; this is how. |
| P12 | No route for the sensor cable out of the cavity, nor for the battery and sensor leads between the two housings; no inlet positions. | The sensor cable leaves through grommets in the liner and can and its own shell slot at the cooling end. A printed cable duct cover on the shell's back face links the two housings. The 12 V and USB-C inlets sit low on the cooling head's end wall; the lid switch is a reed switch inside the head with a magnet in the lid cap. | Keeps every wire out of the VIP joints except the existing crossing; inlet position as recommended for the appearance model (item 3). |

*Table 2. Knock-on changes.*

| Item | Change | Reason |
| --- | --- | --- |
| PCM | 0.972 to 0.935 kg (jacket 0.670, lid 0.265), now measured on the model rather than estimated [C2] | Feet, collar, cable and the tray walls take space; the analytic estimate had ignored them |
| Hold times | No power at 43 °C 14.0 to 13.3 h; off-grid 28.4 to 27.3 h at 32 °C and 17.5 to 16.7 h at 43 °C [D2, F2]. R4, R5 and R6 stay at risk | Less PCM and a slightly larger foam strip (0.093 W/K overall) |
| Refreeze | All PCM 8.4 to 8.0 h, a few minutes over the 8 h target [G4]; R8 still not met | Less PCM to freeze |
| Mass | 5.53 to 5.70 kg empty [K2]; R12 now missed by 0.20 kg | Pads, towers, ears, feet, collar, frame, fillers, duct, cradle, inserts and the folded tray |
| Size | 366 x 212 x 207 to 366 x 220 x 207 mm [A6]; R13 met | Handle pivot pads |
| Cost | $303 to $308 against the $310 value-engineering target [L2]: line 2 $12 to $13, new line 17 at $4; R15 within the target | Parts added for construction |
| Drawings | CPD-DWG-001 Rev P4; making sketches CPD-DWG-101 to 115 added | Follows the model |
| Documents | CPD-CAL-001 v0.4, CPD-REQ-001 v0.6, CPD-PRC-001 v0.6, BOM and BOM notes; new CPD-BLD-001 and CPD-DEC-001 | Follows the model |

*Table 3. Items proposed to Amish; all accepted on 2026-10-02 as recommended in the register (A4 with R-134a named).*

| # | Question | Options | Recommendation |
| --- | --- | --- | --- |
| A1 | Accept the design-for-construction changes in Table 1. | (a) accept; (b) accept with changes. | (a). |
| A2 | Mass: R12 is now missed by 0.20 kg, not 0.03 kg (this replaces the earlier question CPD-DDR-002 N2). Every added gram is a fixing the case needs. | (a) relax R12 to 5.75 kg; (b) keep 5.5 kg and settle it by weighing at TRL 4; (c) look for mass now: a 1.0 mm tray (about 0.05 kg, slower lid refreeze), a lighter handle and strap. | (a), because the extra mass is what it takes to build the case; (c) if the target must stay. Accepted 2026-10-02: R12 is 5.75 kg for the prototype, weighed at TRL 4, with the base bumper left off. |
| A3 | Battery removal (R14 asks for a removable battery or a shipping switch): the pack now comes out by removing the battery bay (four screws) and unplugging the duct leads. | (a) count that as removable for the prototype; (b) add a shipping switch in the bay. | (a) for the prototype; revisit with airline guidance before field use. Accepted 2026-10-02: before any field or air travel use, add the shipping switch and check the carrier's lithium battery rules. |
| A4 | Refrigerant for the loop: CPD-CAL-001 sizes the loop by its conductance and does not name a working fluid, and the charge must be set before the technician fills it. | Choose with the technician, for example R-134a or R-1234yf, by the charge needed and local rules. | Decide with the technician at TRL 4. Accepted 2026-10-02 as changed in the register: R-134a (non-flammable, A1) for the prototype, charge set by the technician from the loop volume; R-1234yf (A2L) only for a product version under local rules. |

## Consequences

- `design_state: constructable` in `project.yaml`. The build plan CPD-BLD-001 shows every component and step in pictures generated from the model (`cad/src/build_plan_media.py`).
- Requirement counts are unchanged at 10 met, 3 at risk, 2 not met (R8, R12), 2 not verifiable at TRL 3 (CPD-CAL-001 v0.4); R12's miss is larger and R8's smaller. With the decisions of 2026-10-02, R12 is relaxed to 5.75 kg and R8 restated as 9 h, so both are met on paper: 12 met, 3 at risk, 2 not verifiable (CPD-REQ-001 v0.8).
- The photoreal renders (`media/render-*.png`), `media/card.png`, `media/social-preview.png` and the appearance model `cad/src/product_model.py` still show the concept handle position, a flat lid plate and no pads, towers, slots or duct; they need regenerating on Amish's Mac, where Blender is.
- Building the loop needs a refrigeration technician; this is called out as a safety stop in the build plan.

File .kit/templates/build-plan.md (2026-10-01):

---
doc_id: PRJ-BLD-001
title: Project prototype build plan
project: Project name
doc_type: Build plan
version: "0.1"
status: Draft
date: YYYY-MM-DD
author: Amish Chadha
license: CERN-OHL-S-2.0
revisions:
  - version: "0.1"
    date: YYYY-MM-DD
    author: Amish Chadha
    change: First build plan; design made constructable
---

# Project prototype build plan

**Plan, not yet built.** How to build the first proof-of-concept prototype, component by component. Building and testing to it is TRL 4 work. Decisions still to be made are kept in the design decisions register (`docs/06-design-decisions.md`), not here.

## 1. What you are building

Every component, pulled apart and numbered in build order

One short paragraph: what the prototype is, how many components, which are made and which are bought, and the main ways they are made.

## 2. What changed to make it buildable

| Component | The concept had | The buildable design has | Why |
| --- | --- | --- | --- |

## 3. Making the components

### 3.1 Component name

Making sketch

**What it is and what it is made from.**

**How to make it.**

1. Mark out ...
2. Cut ...

**How it fits the parts next to it.**

Close-up of the joint

**Check before moving on.**

## 4. Putting it together

### Step 1: ...

Step 1

## 5. First checks

| Check | Requirement | How | Pass when |
| --- | --- | --- | --- |

## 6. Safety stops

## 7. Tools, skills and workspace

## 8. Where the numbers come from

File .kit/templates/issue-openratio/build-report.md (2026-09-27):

---
name: Build report
about: Tell us what happened when you built, printed or tested part of this design
title: "Build report: "
labels: build-report
---

This is a research and educational prototype, not a medical device. It is a TRL 3 concept and is not released for fabrication. If you build any part of it, you do so at your own risk. Reports help everyone.

**What you built** (part, sub-assembly or test)

**Materials, tools and settings**

**What worked**

**What did not work, with photos or measurements if you have them**

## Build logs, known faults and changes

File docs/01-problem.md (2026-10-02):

---
doc_id: CPD-PRB-001
title: ColdPod problem statement
project: ColdPod
doc_type: Problem statement
version: "0.6"
status: Draft
date: '2026-10-02'
author: Amish Chadha
license: CERN-OHL-S-2.0
revisions:
- version: "0.1"
  date: '2026-09-24'
  author: Amish Chadha
  change: Initial scaffold
- version: "0.2"
  date: '2026-09-25'
  author: Amish Chadha
  change: Populate to TRL 2 (problem, users and context, constraints, prior work with sources)
- version: "0.3"
  date: '2026-09-25'
  author: Amish Chadha
  change: Record Amish's decisions (CPD-DDR-001), outreach vaccinators first and budget $300; partner stays open
- version: "0.4"
  date: '2026-09-25'
  author: Amish Chadha
  change: Recommendations accepted by Amish (DDR-002); budget kept at $300; origin of the idea (vaccine vial monitor) added
- version: "0.5"
  date: '2026-09-26'
  author: Amish Chadha
  change: Budget top-up approved by Amish; budget $310
- version: "0.6"
  date: '2026-10-02'
  author: Amish Chadha
  change: "Partner type decided and first candidate to approach (CPD-DEC-001, 2026-10-02)"
---

# ColdPod problem statement

Insulin and vaccines must stay between 2 and 8 °C in transport, but the last leg of the cold chain (a health worker on foot or on a motorbike, or a person with diabetes travelling in a hot place without steady power) relies on ice packs and luck: loads get too warm when the ice runs out, freeze when the ice is too cold, and nobody knows either happened because nothing records the temperature.

## The problem

**Both heat and cold spoil the load.** Unopened insulin keeps its potency until the printed expiry date only when stored at about 2 to 8 °C (36 to 46 °F); it can be kept at 15 to 30 °C (59 to 86 °F) for up to 28 days, loses potency faster above that, and must be thrown away if it has frozen ([US FDA, insulin storage in emergencies](https://www.fda.gov/drugs/emergency-preparedness-drugs/information-regarding-insulin-storage-and-switching-between-products-emergency)). Most routine vaccines have the same 2 to 8 °C window, and several (for example those with an aluminium adjuvant) are damaged by freezing.

**Freezing is common, not rare.** A systematic review found that vaccines were exposed to temperatures below the recommended range in about 33 % of storage studies in wealthier countries and 37 % in lower-income countries, and during shipment in 38 % and 19 % of studies respectively ([Hanson et al., *Vaccine*, 2017](https://www.sciencedirect.com/science/article/pii/S0264410X16309471); an earlier review reached a similar conclusion: [Matthias et al., *Vaccine*, 2007](https://pubmed.ncbi.nlm.nih.gov/17382434/)). Frozen water ice packs placed against vials are a well-known cause, which is why WHO now prequalifies "freeze-free" cold boxes and carriers ([WHO PQS E004/CB05.3](https://extranet.who.int/pqweb/key-resources/documents/pqs-performance-specification-e004cb053-vaccine-cold-box-freeze-prevention)).

**Passive carriers have a fixed clock.** A WHO-prequalified vaccine carrier must keep its load cold for at least 15 h (short range) or 30 h (long range) at a constant +43 °C, and then it needs freshly frozen or conditioned ice packs ([WHO PQS E004/VC01 test protocol](https://extranet.who.int/prequal/key-resources/documents/pqs-independent-type-testing-protocol-e004vc01-vp2-vaccine-carrier)). Where freezers are scarce or power is intermittent, the ice packs are the weak link.

**Monitoring is separate and often missing.** Good practice is a digital data logger with a buffered probe, ±0.5 °C accuracy, logging at least every 30 min and an out-of-range alarm ([CDC Pink Book, chapter 5](https://www.cdc.gov/pinkbook/hcp/table-of-contents/chapter-5-vaccine-storage-and-handling.html)). WHO's 30-day temperature recorders alarm at −0.5 °C or lower for 60 min and at +8 °C or higher for 10 h ([TechNet-21, 30DTR](https://www.technet-21.org/en/temperature-monitoring/finding-the-right-solution/finding-the-right-solution-30dtr)). In a carrier, these are extra devices that are easy to leave behind, and they record a problem rather than prevent it.

**Existing active coolers are closed or costly.** Battery-powered cold chain boxes with built-in monitoring exist, for example the Ember Cube shipping box ([Fast Company](https://www.fastcompany.com/90717041/ember-known-for-keeping-coffee-hot-builds-a-shipping-box-to-keep-vaccines-cold)), and small USB-powered insulin coolers are sold to travellers ([4AllFamily Voyager](https://4allfamily.com/products/portable-medical-fridge-usb-insulin-medicines)). None is an open, inspectable design that a clinic, university group or maker space can build, repair and adapt.

**Indicators record heat, not cold.** The vaccine vial monitor, a heat-sensitive label that WHO and PATH brought into use on oral polio vaccine in 1996 ([PATH](https://www.path.org/our-impact/articles/vaccine-vial-monitor-worlds-smartest-sticker/)), showed how much a cheap indicator travelling with each vial can do, but it does "not measure exposure to freezing temperatures" ([OpenLearn Create, Immunization module](https://www.open.edu/openlearncreate/mod/oucontent/view.php?id=53354&section=1.5.1)). That gap between heat monitoring and freeze protection is the starting point for ColdPod.

The gap ColdPod addresses: an open, repairable carrier that combines passive storage (so it works with no power), active cooling (so it can be topped up from a vehicle, a solar panel or a USB-C charger instead of a freezer) and an integrated logger that raises alarms before a load is lost.

## Users and context

| User | Need | Context |
| --- | --- | --- |
| Outreach vaccinator or community health worker | Carry a day's vaccines to villages and back without freezing or overheating them; know that the load stayed in range | On foot, bicycle or motorbike; 25 to 43 °C; clinic power intermittent; 8 to 12 h trips |
| Person with diabetes | Keep a month's insulin cold while travelling or during power cuts | Hot climates, long journeys, displacement, homes without a refrigerator |
| Pharmacy or clinic running home deliveries | Deliver temperature-sensitive medicines with a record of the trip | Van or motorbike with a 12 V socket |
| Humanitarian or disaster response team | Carry insulin and vaccines where the grid is down | Solar panels, vehicles, generator hours |
| Open hardware and global health researchers | A reproducible, auditable reference design | University labs, maker spaces |

## Constraints

- Garage-buildable prototype, $310 USD or less in parts (raised from $250 to $300 by Amish, 2026-09-25, CPD-DDR-001 D10, and to $310 by Amish, 2026-09-26, CPD-DDR-002 N3; the TRL 3 BOM is $303), using off-the-shelf modules, 3D-printed or hand-made parts, and bought vacuum-insulated panels.
- Carried by one person, by hand or on a shoulder strap.
- Chargeable from a vehicle 12 V socket, a small solar panel or a USB-C Power Delivery (PD) charger; no mains-voltage parts inside the box.
- Battery small enough to carry on a passenger aircraft without airline approval (100 Wh or less per the [FAA PackSafe rules](https://www.faa.gov/hazmat/packsafe/lithium-batteries)).
- Research and educational prototype only. ColdPod is not a medical device, is not WHO-prequalified, and must not be the only protection for real vaccines or insulin.

## Out of scope

- Frozen and ultra-cold products (for example −20 °C or −70 °C vaccines).
- Clinic refrigerators and bulk storage.
- Regulatory prequalification, which would follow only after lab and field validation well beyond TRL 3.
- Cloud services. Data stays on the device and the owner's phone.

## Open questions

- Which user comes first? Decided by Amish, 2026-09-25 (CPD-DDR-001 D11): the outreach vaccinator first, since that user sets the 43 °C design case; the traveller with insulin second.
- Which partner should help shape the requirements? Decided by Amish, 2026-10-02 (CPD-DEC-001): an immunization program, consistent with outreach vaccinators first. First candidate to approach: PATH, or a national immunization program's outreach team reached through it. Nothing is agreed yet.
- How hot does it really get inside a carrier strapped to a motorbike in direct sun? The 43 °C WHO test point is used until field data exists.

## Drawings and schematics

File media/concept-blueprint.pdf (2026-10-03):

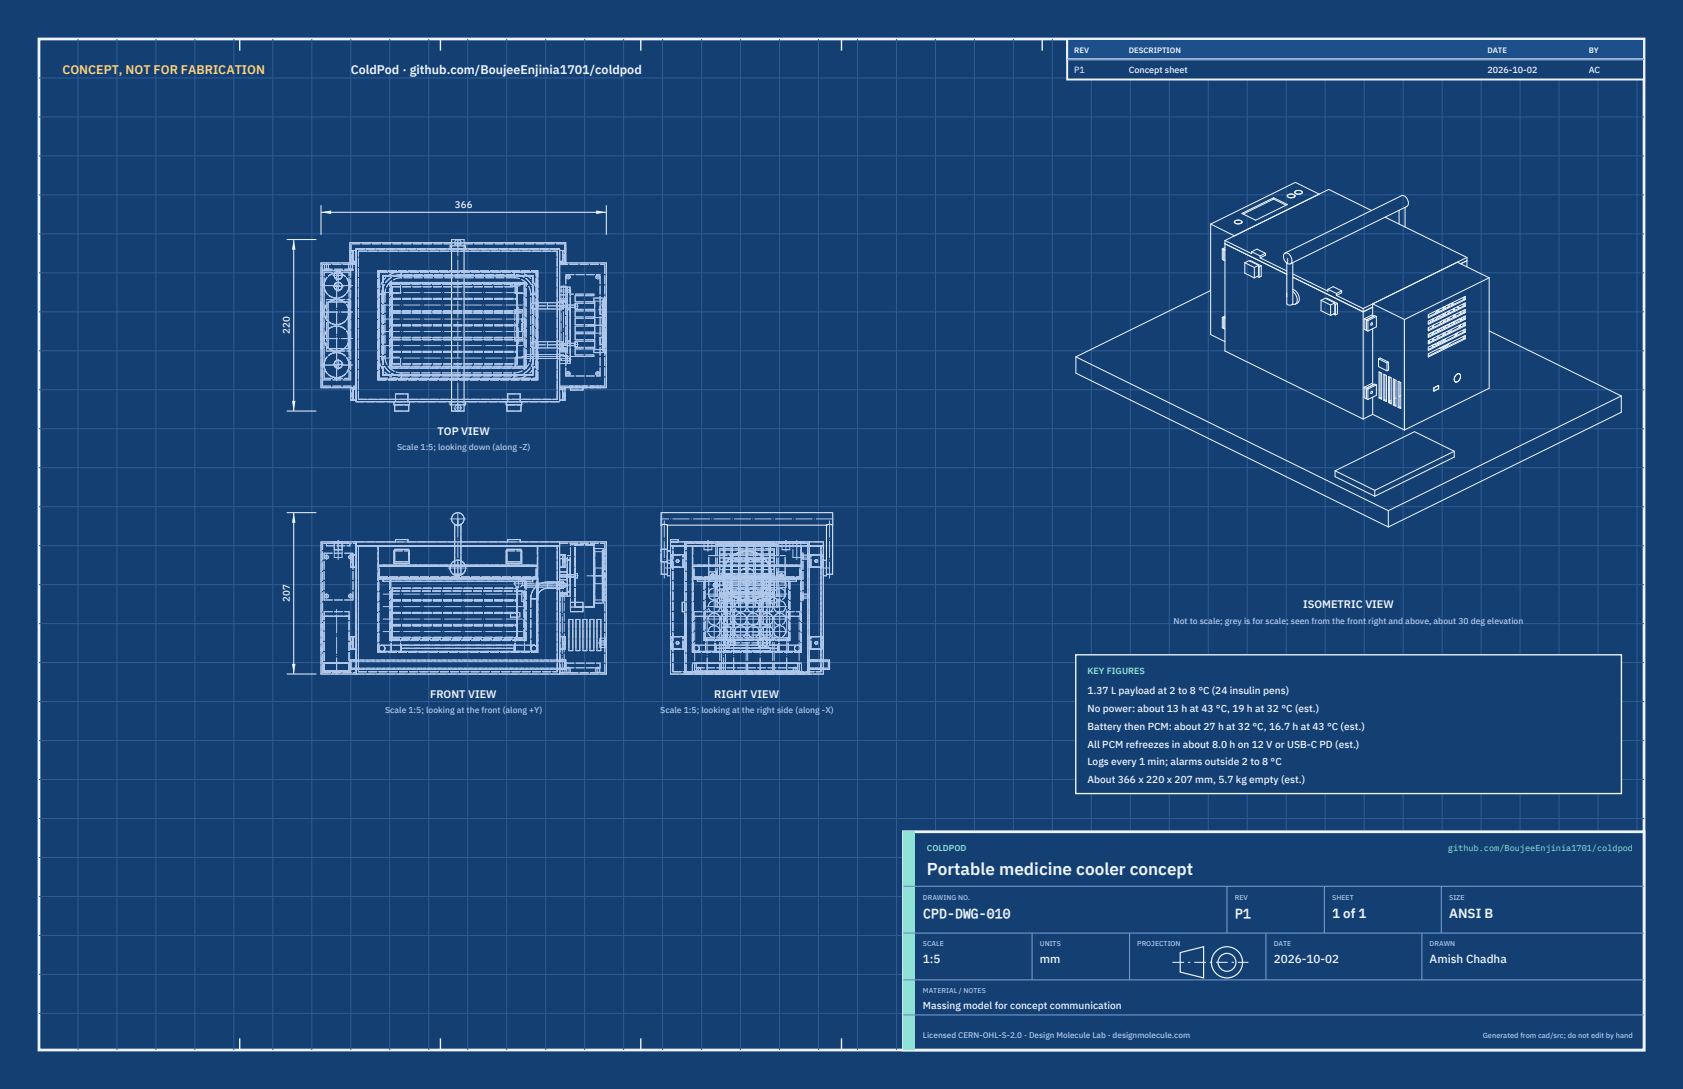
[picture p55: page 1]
CONCEPT, NOT FOR FABRICATION; ColdPod · github.com/BoujeeEnjinia1701/coldpod; FRONT VIEW; TOP VIEW; RIGHT VIEW; ISOMETRIC VIEW; REV; DESCRIPTION; DATE; Concept sheet; COLDPOD; github.com/BoujeeEnjinia1701/coldpod; DRAWING NO. CPD-DWG-010; REV P1; SHEET 1 of 1; SIZE ANSI B; SCALE 1:5; UNITS mm; PROJECTION; DRAWN Amish Chadha; Licensed CERN-OHL-S-2.0 · Design Molecule Lab · designmolecule.com; Generated from cad/src; do not edit by hand

Scale 1:5; looking down (along -Z)

Not to scale; grey is for scale; seen from the front right and above, about 30 deg elevation

KEY FIGURES
1.37 L payload at 2 to 8 °C (24 insulin pens)
No power: about 13 h at 43 °C, 19 h at 32 °C (est.)
Battery then PCM: about 27 h at 32 °C, 16.7 h at 43 °C (est.)
All PCM refreezes in about 8.0 h on 12 V or USB-C PD (est.)
Logs every 1 min; alarms outside 2 to 8 °C
About 366 x 220 x 207 mm, 5.7 kg empty (est.)

Scale 1:5; looking at the front (along +Y)

Scale 1:5; looking at the right side (along -X)

Portable medicine cooler concept

MATERIAL / NOTES
Massing model for concept communication

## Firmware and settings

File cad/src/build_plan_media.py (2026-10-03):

"""ColdPod prototype build plan pictures (CPD-BLD-001, STANDARDS section 18).

Run from the repo root:  python cad/src/build_plan_media.py [overview|vips|sheets|joints|steps|wiring ...]
A sheet, joint or step can be drawn alone: sheets:104, joints:3, steps:12.
With no argument it draws everything. Every picture is drawn from cad/src/model.py
(build_components), so the pictures and the model never disagree:
    docs/05-build-plan/overview.png        every component pulled apart, numbered in build order
    docs/05-build-plan/vip-panels.png      the seven bought VIP panels and the foam strip
    cad/drawings/CPD-DWG-101 to 115        making sketches for the made components
    docs/05-build-plan/joint-NN.png        close-ups of the joints that need explaining
    docs/05-build-plan/step-NN.png         one picture per assembly step
    docs/05-build-plan/wiring.png          block-level wiring with wire sizes (matplotlib)
Uses .kit/build_views.py. BUILD PLAN ILLUSTRATION, PLAN NOT YET BUILT.
"""
import sys
from pathlib import Path

ROOT = Path(__file__).resolve().parents[2]
sys.path[:0] = [str(ROOT / ".kit"), str(ROOT / "cad" / "src")]
import build_views as bv  # noqa: E402
from build_views import Part  # noqa: E402
from model import PARAMS as P, build_components, levels  # noqa: E402
from build123d import Pos  # noqa: E402

OUT = ROOT / "docs" / "05-build-plan"
DWG = ROOT / "cad" / "drawings"
DATE = "2026-10-01"
L = levels(P)
C = build_components(P)

COL = {"shell": "#94A3B8", "fillers": "#475569", "duct": "#64748B", "vip": "#D6D3D1", "foam": "#FCD34D",
       "can": "#9CA3AF", "loop": "#B87333", "block": "#6B7280", "frame": "#0F766E", "drain": "#334155",
       "tec": "#7DD3FC", "sink": "#4B5563", "fan": "#1F2937", "screws": "#111827", "head": "#0E7490",
       "bay": "#0E7490", "lid": "#A1A1AA", "latches": "#111827", "lidplate": "#78716C", "pcm": "#60A5FA",
       "liner": "#A8A29E", "feet": "#7C3AED", "rack": "#F59E0B", "pens": "#F3F4F6", "sensors": "#D4A017",
       "power": "#15803D", "cells": "#C2410C", "cradle": "#7C2D12", "logger": "#1F2937", "display": "#38BDF8",
       "handle": "#374151"}


def _fuse(shapes):
    out = None
    for s in shapes:
        out = s if out is None else out + s
    return out


def S(*ks):
    return _fuse([C[k].shape for k in ks])


def part(name, shape, color, explode=(0, 0, 0), alpha=1.0):
    return Part(name, shape, color, None, tuple(explode), alpha)


def mv(p, e):
    return Part(p.name, p.shape, p.color, None, tuple(e), p.alpha)


VIPS = ("vip_floor", "vip_front", "vip_back", "vip_endm", "vip_endlo")


# ----------------------------------------------------------------- named parts, in build order
def made():
    return {
        "shell": part("Outer shell and slot fillers", S("shell", "fillers"), COL["shell"]),
        "vips": part("VIP panels, body (6)", S(*VIPS, "vip_endhi"), COL["vip"]),
        "can": part("Evaporator can", C["can"].shape, COL["can"]),
        "loop": part("Loop thermosiphon", C["loop"].shape, COL["loop"]),
        "block": part("Cold block and charge stub", S("block", "charge"), COL["block"]),
        "foam": part("Foam strip", C["foam"].shape, COL["foam"]),
        "jacket": part("PCM jacket pouches", C["pcm_jacket"].shape, COL["pcm"]),
        "feet": part("Liner feet and collar", S("feet", "collar"), COL["feet"]),
        "liner": part("Liner, probes and liner cut-out", S("liner", "liner_probe", "cutout"), COL["liner"]),
        "rack": part("Payload rack and payload probe", S("rack", "probe"), COL["rack"]),
        "frame": part("Block frame and drip tray", S("frame", "drain"), COL["frame"]),
        "tec": part("Peltier module", C["tec"].shape, COL["tec"]),
        "sink": part("Heat sink, fan and guard", S("sink", "fan", "guard"), COL["sink"]),
        "power": part("Power board, inlets, ambient sensor", S("power", "power_so", "inlets", "ambient"), COL["power"]),
        "head": part("Cooling head housing", C["head"].shape, COL["head"]),
        "cells": part("Cell cradle, cells and BMS", S("cradle", "cells"), COL["cells"]),
        "logger": part("Logger, display, status lights, shipping switch", S("logger", "logger_so", "display", "alarm", "alarm2", "shipswitch"), COL["display"]),
        "bay": part("Battery bay housing", C["bay"].shape, COL["bay"]),
        "duct": part("Cable duct cover", C["duct"].shape, COL["duct"]),
        "handle": part("Handle and latches", S("handle", "latches"), COL["handle"]),
        "tray": part("Lid cold plate tray and lid pack", S("lidplate", "pcm_lid"), COL["lidplate"]),
        "plug": part("VIP lid plug", C["vip_lid"].shape, COL["vip"]),
        "lid": part("Lid cap", C["lid"].shape, COL["lid"]),
    }


# ----------------------------------------------------------------- overview
def overview():
    M = made()
    off = {"shell": (0, 0, 0), "vips": (0, 0, 170), "can": (0, 0, 430), "loop": (0, 0, 310), "block": (0, 0, 310),
           "foam": (110, 0, 170), "jacket": (0, 0, 590), "feet": (0, 0, 690), "liner": (0, 0, 750), "rack": (0, 0, 870),
           "frame": (170, 0, 0), "tec": (240, 0, 0), "sink": (310, 0, 0), "power": (380, 0, -110), "head": (470, 0, 0),
           "cells": (-170, 0, 0), "logger": (-250, 0, 80), "bay": (-340, 0, 0), "duct": (0, 0, -120),
           "handle": (-360, 0, 470), "tray": (0, 0, 1010), "plug": (0, 0, 1110), "lid": (0, 0, 1200)}
    parts = []
    for k, p in M.items():
        p.explode = off[k]
        parts.append(p)
    return bv.overview(parts, OUT / "overview.png", "ColdPod prototype: every component, pulled apart",
                       subtitle="Numbered in build order. Seen from the front right and above; the cooling head is on the right",
                       elev=16, azim=-62, size=(11, 10), dpi=150, key=True)


def vips():
    parts = [part("Floor panel 255 x 190", C["vip_floor"].shape, "#D6D3D1", (0, 0, 0)),
             part("Front panel 255 x 136.5", C["vip_front"].shape, "#C7C2BD", (0, -90, 30)),
             part("Back panel 255 x 136.5", C["vip_back"].shape, "#C7C2BD", (0, 90, 30)),
             part("Battery end panel 140 x 136.5", C["vip_endm"].shape, "#E7E5E4", (-100, 0, 30)),
             part("Cooling end, lower 140 x 68", C["vip_endlo"].shape, "#E7E5E4", (100, 0, 30)),
             part("Foam strip, cut round the pipes", C["foam"].shape, COL["foam"], (100, 0, 70)),
             part("Cooling end, upper 140 x 40.5", C["vip_endhi"].shape, "#E7E5E4", (100, 0, 110)),
             part("Lid plug 204 x 139", C["vip_lid"].shape, "#D6D3D1", (0, 0, 170))]
    return bv.overview(parts, OUT / "vip-panels.png", "Vacuum-insulated panels: the seven bought panels and the foam strip",
                       subtitle="All 25 mm thick, sizes in mm. Ordered to size: never cut, drill or pierce a VIP",
                       elev=22, azim=-58, size=(10, 7), dpi=150)


# ----------------------------------------------------------------- making sketches
def sheets(only=None):
    import build123d as b
    base = dict(project="ColdPod", date=DATE)
    M = made()
    g = lambda *ks: [part(C[k].name, C[k].shape, "#D1D5DB") for k in ks]  # noqa: E731
    specs = []
    sx, ez = L["sh_x"], P["pipe_exit_z"]

    specs.append((101, dict(
        part=part("Outer shell", C["shell"].shape, COL["shell"]), neighbours=g(*VIPS, "head", "bay", "lid"),
        title="ColdPod outer shell: making sketch", material="PETG or ASA, 3D printed, 4 perimeters, 25 % infill",
        inset_view=(22, -50),
        notes=["Print as one tub, open side up: 261 x 196 x 164.5 mm outside the walls",
               "  (275 x 204 over pads and towers), 3 mm walls and floor. Needs a",
               "  printer bed of at least 300 x 300 mm.",
               "Cooling end (right): two pipe slots 10 wide, 25 each side of the centre,",
               "  and a cable slot 6 wide, 40 toward the front, each open at the rim and",
               "  ending in a half-round at 114 up.",
               "Pads 14 x 16 x 4 proud on both end faces, 89 each side of centre,",
               "  centred 40 and 145 up; one M3 heat-set insert in each.",
               "Two towers 10 x 10 x 10 on the cooling end, 44 each side, 126 up; M3 insert.",
               "Handle pads 20 dia x 4 at the middle of front and back, 136 up; M5 insert.",
               "Latch pads 20 x 16 x 4 on the front, 72 each side, 142 to 158 up; 2 x M3.",
               "Set every insert with the soldering iron before any VIP goes in.",
               "No screw or drill may ever go through a wall: a VIP sits behind it.",
               "Check: the inside is 255 x 190, square, within 0.5 mm."])))
    specs.append((102, dict(
        part=part("Evaporator can", C["can"].shape, COL["can"]), neighbours=g("vip_floor", "loop"),
        title="ColdPod evaporator can: making sketch", material="Aluminium sheet 1.0 mm, 5052 or 3003",
        inset_view=(28, -50),
        notes=["Open box 205 x 140 x 95 mm outside, 1.0 mm sheet, folded from one",
               "  cross-shaped blank by a sheet metal shop; TIG weld the four corners.",
               "Fold a 5 mm flange inward all round the rim, last. It is the landing",
               "  for the lid cold plate tray and must be flat within 0.3 mm.",
               "Cooling end wall: two riser slots 9 wide, 25 each side of centre,",
               "  open at the rim and running down to 67.5 mm above the floor.",
               "Cable hole 6 mm, 40 toward the front, 86 up; fit a grommet.",
               "Deburr every edge: the pouches must not be cut.",
               "Fit: stands on the VIP floor panel; its walls touch the VIP walls.",
               "Check: the inside is 203 x 138 and square; the rim flange lies flat."])))
    specs.append((103, dict(
        part=part("Loop thermosiphon", C["loop"].shape, COL["loop"]), neighbours=g("block", "vip_floor"),
        title="ColdPod loop thermosiphon: bending sketch", material="Soft copper refrigeration tube 8 x 0.5 mm",
        inset_view=(28, -50),
        notes=["Evaporator ring: a closed rectangle 195 x 130 mm on the tube centre line,",
               "  corners bent to 25 mm radius, ends joined with a coupler, brazed.",
               "Two tees in the cooling-end run, 25 mm each side of the centre.",
               "Risers: from each tee straight up 63.5 mm, then a 90 degree bend of",
               "  17.5 mm radius (lever bender for 8 mm tube) toward the cooling end;",
               "  the tail ends 33 mm beyond the outside of the can.",
               "Braze with silver alloy, nitrogen purge; clean and cap the open ends.",
               "Fit: the ring lies in the bottom inside corner of the can, touching",
               "  floor and wall, bonded with thermally conductive epoxy; the risers",
               "  drop down the can's open slots; the tails go into the cold block.",
               "A refrigeration technician leak tests, evacuates and charges the loop.",
               "Check: the ring lies flat on a table within 1 mm."])))
    specs.append((104, dict(
        part=part("Cold block", S("block", "charge"), COL["block"]), neighbours=g("loop", "tec", "can"),
        title="ColdPod cold block: making sketch", material="Aluminium 6061, 10 x 60 x 44 mm",
        view_shape=C["block"].shape, inset_view=(20, -35),
        notes=["Mill a block 10 x 60 x 44 mm; lap the front face flat (Peltier side).",
               "Back face (against the shell): two tube sockets 8.1 mm, 5 deep, 25",
               "  each side of centre, 10 up from the bottom edge.",
               "Condensing passage: 6 mm, drilled from the back-side end face, 5 mm",
               "  in from the back face and 10 up, through both sockets.",
               "Front face: two M3 tapped holes 8 deep, 24.5 each side, 22 up.",
               "Join the loop tails into the sockets and a 6 mm copper charge stub",
               "  into the passage mouth with aluminium-to-copper brazing rod.",
               "After charging, the stub is pinched shut and brazed.",
               "Fit: back face flat on the shell end, over the slot fillers; held by",
               "  the block frame (CPD-DWG-109). Wrap its edges in foam tape.",
               "Check: front face flat within 0.05 mm."])))
    specs.append((105, dict(
        part=part("Slot fillers", C["fillers"].shape, COL["fillers"]), neighbours=g("shell", "loop", "block"),
        title="ColdPod slot fillers (make 3): making sketch", material="PETG, 3D printed, 100 % infill",
        view_shape=C["fillers"].shape, inset_view=(15, -30),
        notes=["Two pipe fillers 3 x 10 mm and one cable filler 3 x 6 mm, each 50.5",
               "  tall, with a half-round notch at the bottom: 9 mm across for the",
               "  pipes, 6 mm for the cable.",
               "Print lying flat.",
               "Fit: slide each filler down its shell slot onto the pipe or cable",
               "  after the foam strip and the upper VIP end panel are in. Glue the",
               "  sides with a bead of silicone; the outer face is flush with the shell.",
               "Check: flush within 0.3 mm, so the cold block sits flat on it."])))
    specs.append((106, dict(
        part=part("Liner", C["liner"].shape, COL["liner"]), neighbours=g("feet", "collar", "rack", "can"),
        title="ColdPod liner: making sketch", material="Aluminium sheet 1.5 mm, 5052",
        inset_view=(28, -50),
        notes=["Open box 175 x 110 x 80 mm outside, 1.5 mm sheet, folded from one",
               "  blank by a sheet metal shop; TIG weld the four corners.",
               "Cable hole 6 mm in the cooling-end wall, 40 toward the front, 71 up;",
               "  fit a grommet.",
               "Deburr all edges; round the top edge so it cannot cut a hand.",
               "Glue the four feet under it and the collar round its top",
               "  (CPD-DWG-107) with two-part epoxy.",
               "Clip the liner probe inside the back wall and the 3 degree cut-out",
               "  inside the cooling-end wall (thermal paste under each).",
               "Fit: stands on its feet on the can floor; the collar centres it",
               "  inside the can's rim flange with 0.5 mm all round.",
               "Check: inside 172 x 107 x 78.5; the top edge flat within 0.3 mm."])))
    specs.append((107, dict(
        part=part("Liner feet and collar", S("feet", "collar"), COL["feet"]), neighbours=g("liner", "can"),
        title="ColdPod liner feet (make 4) and collar: making sketch", material="PETG, 3D printed, 100 % infill",
        inset_view=(28, -50),
        notes=["Feet: four blocks 12 x 12 x 14 mm.",
               "Collar: a frame 192 x 127 mm outside, 175 x 110 inside, 4 mm tall.",
               "Print the collar flat. It insulates: never use metal here.",
               "Fit: glue a foot under each corner of the liner, 8 mm in from both",
               "  edges. Glue the collar round the liner with its top flush with the",
               "  liner's top edge.",
               "The feet stand on the can floor and keep the liner 14 mm above it;",
               "  the floor pouch has a relief at each foot.",
               "Check: the liner stands level on its feet within 0.5 mm."])))
    specs.append((108, dict(
        part=part("Payload rack", C["rack"].shape, COL["rack"]), neighbours=g("liner", "probe"),
        title="ColdPod payload rack: making sketch", material="PETG, 3D printed",
        inset_view=(28, -50),
        notes=["Floor 170 x 105 x 2 mm with two dividers 2 mm thick and 60 tall,",
               "  17 mm each side of the centre, running the full length.",
               "Holds 24 pens of 16 mm, three pairs across and four layers up.",
               "Print floor down.",
               "Fit: drops into the liner with 1 mm all round.",
               "The payload probe vial (10 x 40 mm) lies across the top layer at the",
               "  cooling end, held by its clip on the liner end wall.",
               "Check: a 16 mm rod slides freely between each divider and the wall."])))
    specs.append((109, dict(
        part=part("Block frame and drip tray", C["frame"].shape, COL["frame"]), neighbours=g("block", "tec", "can", "loop"),
        title="ColdPod block frame and drip tray: making sketch", material="PETG, 3D printed, 100 % infill",
        view_shape=C["frame"].shape, inset_view=(20, -35),
        notes=["Plate 98 x 52 x 3.5 mm with a 42 x 42 window for the Peltier module.",
               "Four 3.5 mm holes 26 up from the bottom edge: two at 24.5 each side",
               "  (module clamp screws pass) and two at 44 each side (frame screws).",
               "Drip tray along the bottom edge: floor 68 x 13.5 x 2 mm with 2 mm",
               "  lips at both ends, reaching back to the shell.",
               "Drain hole 5 mm, 3.5 mm from the shell end, 30 toward the front.",
               "The plate is thinner than the module (4 mm), so the clamp force goes",
               "  through the module, not the frame.",
               "Fit: plate on the block's front rim; M3 screws into the shell towers.",
               "Check: 0.5 mm gap between the plate and the heat sink."])))
    specs.append((110, dict(
        part=part("Cooling head housing", C["head"].shape, COL["head"]), neighbours=g("shell", "sink", "fan", "power"),
        title="ColdPod cooling head housing: making sketch", material="PETG or ASA, 3D printed, 2 mm walls",
        inset_view=(24, -40),
        notes=["Box 60 x 160 x 169.5 mm, 2 mm walls, open on the shell side.",
               "End wall: seven grille slots 70 x 5 at 10 mm pitch from 94 up; 12 V",
               "  socket hole 12 mm and USB-C slot 9 x 5, both 40 up, 20 each side.",
               "Front: five intake slots 5 x 40, from 30 up. Floor: 5 mm drain hole",
               "  3.5 from the shell end, 30 toward the front; four 3.4 mm holes for",
               "  the power board standoffs, 11 from each end, 62 each side.",
               "Back wall: notch 8 x 12 at the shell end, 6 up, for the cable duct.",
               "Four ears 3 mm thick on the side walls, 3.4 mm holes at 89 each side,",
               "  40 and 145 up.",
               "Fit: open edge against the shell end; four M3 screws through the",
               "  ears into the shell pads.",
               "Check: the ears sit flat on all four pads at once."])))
    specs.append((111, dict(
        part=part("Cell cradle", C["cradle"].shape, COL["cradle"]), neighbours=g("cells", "bay"),
        title="ColdPod cell cradle: making sketch", material="PETG, 3D printed",
        inset_view=(28, -50),
        notes=["Block 36 x 140 x 12 mm with four pockets 32.4 mm across and",
               "  10 deep on a 34 mm pitch; 2 mm floor under each pocket.",
               "Drill two 3.4 mm screw holes between the middle pockets for the bay floor.",
               "Fit: screwed to the bay floor against the end wall; the four cells",
               "  stand in the pockets, the BMS sits on top of them, and a hook and",
               "  loop strap holds the pack down.",
               "Check: each cell drops in without force and does not rattle."])))
    specs.append((112, dict(
        part=part("Battery bay housing", C["bay"].shape, COL["bay"]), neighbours=g("shell", "cells", "cradle", "logger"),
        title="ColdPod battery bay housing: making sketch", material="PETG or ASA, 3D printed, 2 mm walls",
        inset_view=(24, -130),
        rev="P2", revisions=[("P1", "Making sketch for the build plan", DATE, "AC"),
                             ("P2", "Second status light hole and shipping switch hole", "2026-10-02", "AC")],
        notes=["Box 45 x 160 x 169.5 mm, 2 mm walls, open on the shell side.",
               "End wall: four vent slots 60 x 4 from 30 up.",
               "Top: display window 26 x 60, 9 mm from the end wall; 10.4 mm holes",
               "  for the two status lights, 22 from the end wall, 50 toward the back",
               "  and 50 toward the front; 10.4 mm hole for the shipping switch, 22",
               "  from the end wall, 64 toward the back.",
               "Back wall: notch 8 x 12 at the shell end, 6 up, for the cable duct;",
               "  four 3.4 mm holes for the logger standoffs.",
               "Four ears like the cooling head's, mirrored.",
               "Fit: four M3 screws through the ears into the shell pads.",
               "Check: the display window lines up with the display's active area."])))
    specs.append((113, dict(
        part=part("Cable duct cover", C["duct"].shape, COL["duct"]), neighbours=g("shell", "head", "bay"),
        title="ColdPod cable duct cover: making sketch", material="PETG, 3D printed",
        inset_view=(20, 130),
        notes=["A U-channel 8 deep x 12 tall with 1.5 mm walls, open toward the",
               "  shell: 261 mm along the back face, turning 26 mm along each end face.",
               "Print in three pieces (back run and two corners) and glue them.",
               "Fit: lay the battery and sensor leads along the back face 6 to 18 mm",
               "  up, then glue the cover over them with silicone along both edges.",
               "  Each end turns into the notch in its housing's back wall.",
               "Check: no wire is pinched under an edge."])))
    specs.append((114, dict(
        part=part("Lid cold plate tray", C["lidplate"].shape, COL["lidplate"]), neighbours=g("vip_lid", "lid"),
        title="ColdPod lid cold plate tray: making sketch", material="Aluminium sheet 1.5 mm, 5052",
        inset_view=(-20, -50),
        notes=["A shallow tray 204 x 139 mm outside, 16.5 mm deep, folded from one",
               "  1.5 mm blank; the corners are notched and left open.",
               "Fold a 6 mm lip inward all round the top edge.",
               "Bottom flat within 0.3 mm: it lands on the can's rim flange.",
               "Fit: the lid PCM pack goes in through the lip opening; the lip is",
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

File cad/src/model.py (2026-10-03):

"""ColdPod parametric model (build123d), TRL 3, constructable design (CPD-DDR-003).

Run from the repo root:
    python cad/src/model.py            export STEP and STL into cad/step and cad/stl
    python cad/src/model.py --check    run the constructability checks (contacts and clearances)

Exports:
    coldpod-assembly.step / .stl      whole case, lid closed, handle up
    shell.step, lid.step, vip-set.step, liner-rack.step, evaporator-thermosiphon.step,
    cooling-head.step (Peltier, sink, fan, cold block) and end-housings.step (and .stl)

Axes: X along the case length (battery and electronics bay at -X, cooling head at +X),
Y front (-Y) to back (+Y), Z up, table at Z = 0. Units mm.

Layers from the inside out: payload cavity in an aluminium liner standing on four printed
feet and centred by a printed collar; a phase-change material (PCM) jacket in sealed pouches
inside an aluminium evaporator can with a 5 mm inward rim flange; a lid PCM pack in an
aluminium cold plate tray that lands on that flange when the lid closes; seven 25 mm
vacuum-insulated panels (VIP) and a foam strip where the pipes cross; a printed shell (3 mm
walls, 5 mm lid cap, 2 mm end housings, CPD-DDR-002). The shell carries printed pads and
towers with heat-set inserts for every outside fixing, because no screw may pass through a
wall with a VIP behind it. A two-phase loop thermosiphon (evaporator loop bonded into the
bottom inside corner of the can, two bent risers through the foam strip) carries heat one
way, up and out, to an aluminium cold block on the Peltier module in the +X cooling head.

build_components() returns every component separately (the build plan draws from it);
build_parts() groups them into the 17 concept groups used by the concept media, the
appearance model and the calculation note. Not for fabrication: TRL 3 sizes only.
The same PARAMS feed docs/04-calcs/sizing.py (CPD-CAL-001).
"""
import math
import sys
from collections import namedtuple
from pathlib import Path

# Top-level parameters (mm). Edit these, not the geometry below.
PARAMS = {
    # payload cavity and liner (outside of the liner)
    "cav_l": 175.0, "cav_w": 110.0, "cav_h": 80.0, "liner_t": 1.5,
    "rack_t": 2.0,                            # rack floor and divider thickness
    # PCM jacket (includes the evaporator can wall) and lid pack
    "pcm_t": 15.0, "can_t": 1.0, "lid_pcm_t": 15.0,
    "can_flange": 5.0,                        # inward fold at the can rim: the landing for the lid tray (DDR-003)
    "lid_plate_t": 1.5,                       # aluminium lid cold plate, folded into a tray (DDR-003)
    "tray_clear": 0.5, "tray_lip": 6.0,       # tray clearance to the VIP opening; inward top lip bonded to the lid plug
    "foot": 12.0, "collar_h": 4.0,            # printed liner feet (on the can floor) and top collar (DDR-003)
    # insulation and shell (thinner printed parts, CPD-DDR-002)
    "vip_t": 25.0, "shell_t": 3.0, "lid_cap_t": 5.0,
    "foam_strip": 28.0, "foam_lo": 18.0,      # foam strip in the +X VIP wall where the pipes cross, from 18 below to 10 above the pipes
    "pad_t": 4.0, "pad_y": 89.0, "pad_z": (40.0, 145.0),   # printed pads with M3 inserts for the end housings
    "tower": 10.0, "tower_y": 44.0,           # printed towers for the cold block frame
    "slot_w": 10.0,                           # shell pipe slots, open to the rim (DDR-003)
    "handle_pad_z": 136.0, "latch_x": 72.0,
    # payload (not supplied): insulin pens in layers
    "pen_d": 16.0, "pen_l": 160.0, "pen_cols": 6, "pen_layers": 4,
    "probe": (10.0, 40.0),                    # buffered payload probe vial, dia x length, above the top layer (DDR-003)
    # thermosiphon (two-phase loop): 8 mm copper tube
    "pipe_d": 8.0, "pipe_y": 25.0, "loop_inset": 0.0, "pipe_exit_z": 114.0,
    "loop_r": 25.0, "riser_r": 17.5,          # bend radii of the loop corners and of the riser bends
    "socket": 5.0,                            # depth of the tube sockets in the cold block
    "cable_d": 5.0, "cable_y": -40.0,         # sensor cable out of the cavity
    # cold block, Peltier module, heat sink, fan
    "block": (10.0, 60.0, 44.0),              # aluminium, X, Y, Z; bottom at pipe_exit_z - 10
    "tec": (4.0, 40.0, 40.0),                 # 40 x 40 mm module
    "frame_t": 3.5,                           # printed block frame, thinner than the module
    "sink_base": 6.0, "sink_fin": 24.0, "sink_w": 80.0, "sink_h": 80.0, "fins": 9,
    "fan": (10.0, 70.0, 70.0),
    "tec_screw_y": 24.5,
    # end housings
    "head_l": 60.0, "bay_l": 45.0, "end_w": 160.0, "end_wall": 2.0,
    "duct": (8.0, 6.0, 18.0),                 # cable duct cover: depth, bottom, top (DDR-003)
    # battery: 4S1P 32700 LiFePO4 cells standing in the -X bay
    "cell_d": 32.0, "cell_h": 70.0, "cells": 4,
    # bail handle (up position)
    "handle_d": 16.0, "handle_top": 199.0, "handle_pivot_z": 128.0,
}

Comp = namedtuple("Comp", "name shape bom group kind")


def levels(P=PARAMS):
    """Derived half widths (X, Y) and Z levels of each layer."""
    d = {}
    d["cav_x"], d["cav_y"] = P["cav_l"] / 2, P["cav_w"] / 2
    d["pcm_x"], d["pcm_y"] = d["cav_x"] + P["pcm_t"], d["cav_y"] + P["pcm_t"]
    d["vip_x"], d["vip_y"] = d["pcm_x"] + P["vip_t"], d["pcm_y"] + P["vip_t"]
    d["sh_x"], d["sh_y"] = d["vip_x"] + P["shell_t"], d["vip_y"] + P["shell_t"]
    d["vip_z0"] = P["shell_t"]
    d["pcm_z0"] = d["vip_z0"] + P["vip_t"]
    d["cav_z0"] = d["pcm_z0"] + P["pcm_t"]
    d["cav_z1"] = d["cav_z0"] + P["cav_h"]
    d["plate_z1"] = d["cav_z1"] + P["lid_plate_t"]
    d["lidpcm_z1"] = d["plate_z1"] + P["lid_pcm_t"]
    d["rim"] = d["lidpcm_z1"] + P["vip_t"]
    d["lid_top"] = d["rim"] + P["lid_cap_t"]
    d["loop_z"] = d["pcm_z0"] + P["can_t"] + P["loop_inset"] + P["pipe_d"] / 2
    d["block_z0"] = P["pipe_exit_z"] - 10.0
    d["block_zc"] = d["block_z0"] + P["block"][2] / 2
    d["head_x1"] = d["sh_x"] + P["head_l"]
    d["bay_x0"] = -d["sh_x"] - P["bay_l"]
    d["loop_x"] = d["pcm_x"] - P["can_t"] - P["loop_inset"] - P["pipe_d"] / 2
    d["loop_y"] = d["pcm_y"] - P["can_t"] - P["loop_inset"] - P["pipe_d"] / 2
    d["tube_end_x"] = d["sh_x"] + P["socket"]
    return d


def _box(x0, x1, y0, y1, z0, z1):
    from build123d import Box, Pos
    return Pos((x0 + x1) / 2, (y0 + y1) / 2, (z0 + z1) / 2) * Box(x1 - x0, y1 - y0, z1 - z0)


def _tube(p1, p2, r):
    from build123d import Solid, Plane, Vector
    v = Vector(*p2) - Vector(*p1)
    return Solid.make_cylinder(r, v.length, Plane(origin=p1, z_dir=v))


def _xcyl(x0, x1, y, z, r):
    return _tube((x0, y, z), (x1, y, z), r)


def _ycyl(x, y0, y1, z, r):
    return _tube((x, y0, z), (x, y1, z), r)


def _zcyl(x, y, z0, z1, r):
    return _tube((x, y, z0), (x, y, z1), r)
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

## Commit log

2026-09-24 Initial scaffold: standard open hardware layout, CERN-OHL-S v2 + MIT licenses
    Claude-Session: https://claude.ai/code/session_01XuhhSU4W6fYhgCfURbrkut
    [bom.csv]
2026-09-25 Adopt portfolio kit v1.3.0: session commands, scale figure, 3D viewer, flow diagrams
    Adds .claude/commands (/populate, /advance-trl3, /rein-in, /refresh-media)
    so every Claude Code session starts from the standard prompts, and extends
    concept media with a 1.75 m scale figure, an interactive glTF viewer and
    system or energy flow diagrams. TRL cap 3 unchanged.
    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
2026-09-25 Kit v1.3.1: renderer fixes from the TremorTrace pilot
    Context scale parts for small objects, cutaway exclusions, and text
    labels in flow diagrams.
    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
2026-09-25 Populate coldpod to a strong TRL 2 with concept media (overnight batches 4 and 5)
    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
    [bom.csv]
2026-09-25 Advance coldpod to TRL 3 (batches 5 and 6)
    Decisions approved by Amish 2026-09-25 recorded in DDR-001. TRL 4 is on hold.
    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
    [bom.csv, coldpod-assembly.step, coldpod-assembly.stl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]
2026-09-26 Accept all recommendations (DDR-002), switch footer to designmolecule.com, add README write-up with new inspiration point
    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
    [bom.csv, coldpod-assembly.step, coldpod-assembly.stl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]
2026-09-27 Product appearance model and photoreal renders
    Adds cad/src/product_model.py (appearance model for renders only, all main
    dimensions from model.py) and Blender renders in media/render-*.png,
    captioned with the project, repository and viewing direction. README leads
    with the product render; trl stays 3.
    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
2026-10-01 Image quality pass: legible exploded views, flow diagrams and drawing sheets
    Kit 1.6.1 image layout: the parts list sits in its own column, number bubbles sit on visible parts and never overlap, small parts get a leader, pictures are cropped to the subject, flow labels keep numbers with their units, and sheet captions and the revision table no longer overprint. Concept images, blueprint and general arrangement sheet regenerated; repo-specific labels moved clear of other text and lines.
    [sheets.py]
2026-10-01 Kit 1.7.0: constructable design, illustrated build plan and design decisions register
    The design is now constructable: every part can be made and fits its neighbours, with each change recorded in a Design for construction decision record (made under Amish's 2026-09-30 instruction; ope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
    [bom.csv, coldpod-assembly.step, coldpod-assembly.stl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]
2026-10-01 Budget treated as a value-engineering target
    Amish, 2026-10-01: the budget is a hypothetical control target that keeps the design on a value-engineering lens, not a spending limit. Documents now state the value-engineering target and the estima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
2026-10-02 Record Amish's approval of the open-decision recommendations
    Amish approved the recommendation on every open decision in the design decisions register ("i approve your recommendations for all 555 open decisions.", 2026-10-02). Each decision is moved to Decisio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
2026-10-03 Carry approved follow-ups into the design and redo photoreal renders
    Amish approved the follow-up actions from the open-decision sign-off ("APPROVED CHANGES, COMPLETE THESE", 2026-10-02), the design-for-construction change tables in ten repos, the last wave's open dec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
    [bom.csv, coldpod-assembly.step, coldpod-assembly.stl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]
2026-10-03 Record Amish's 2026-10-03 decisions; FlatTrike fork and PotPress guard fixes
    Amish, 2026-10-03: "PalletPilot - i accept it"; "FlatTrike - i accept your design recommendation, proceed and execute the solution for fork direction or caster"; "PotPress - move forward with the four guard fixes. I accept the cost."; "GravitySort - i accept your recommendation"; "TIght Margins - i accept the margins"; "Cost over target - i accept all the cost variations and overruns". FlatTrike knuckle forks turned to trail (35 mm trail); PotPress finer mesh, small-hole plates, top beam and crank bracket covers, ISO 13857 desk check now met on paper. Registers, requirements, drawings, pictures, renders and PDFs upd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

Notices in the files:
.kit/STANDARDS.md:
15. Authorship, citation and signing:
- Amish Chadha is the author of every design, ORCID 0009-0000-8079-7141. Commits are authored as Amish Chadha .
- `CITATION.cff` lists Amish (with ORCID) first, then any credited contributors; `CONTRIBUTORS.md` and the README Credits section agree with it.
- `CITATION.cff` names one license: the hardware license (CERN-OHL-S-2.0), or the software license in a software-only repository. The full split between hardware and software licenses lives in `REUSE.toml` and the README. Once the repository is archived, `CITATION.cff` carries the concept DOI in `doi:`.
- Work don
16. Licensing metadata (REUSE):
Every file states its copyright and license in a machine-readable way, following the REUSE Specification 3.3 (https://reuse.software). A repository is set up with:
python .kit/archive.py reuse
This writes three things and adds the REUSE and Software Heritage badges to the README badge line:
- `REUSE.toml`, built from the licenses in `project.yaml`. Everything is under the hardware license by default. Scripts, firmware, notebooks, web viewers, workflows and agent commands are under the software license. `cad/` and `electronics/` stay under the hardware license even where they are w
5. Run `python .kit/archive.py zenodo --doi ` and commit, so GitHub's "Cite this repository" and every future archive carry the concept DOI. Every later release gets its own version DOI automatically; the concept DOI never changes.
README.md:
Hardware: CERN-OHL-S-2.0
